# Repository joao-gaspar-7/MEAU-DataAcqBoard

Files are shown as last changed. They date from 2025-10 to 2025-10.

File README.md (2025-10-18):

# Embedded Hardware Development Workflow

This repository contains a simplified version of the typical workflow when developing hardware for an embedded system based on a microcontroller.

---

## 🧩 Overview

The goal of this repository is to provide an overview of a typical workflow for:

- **Requirement definition stage** (system specifications, component selection, definition of validation tests)
- **Hardware design stage** (schematics, PCB layout, and fabrication)
- **Testing and validation stage** (board bring-up, unit, integration, and HIL testing)

---

## 📁 Repository Structure

<pre>
├── <a href="0_Requirements">0_Requirements/</a>
│
├── <a href="1_Design-Data">1_Design-Data/</a>
│   ├── <a href="1_Design-Data/0_Hardware">0_Hardware/</a>
│   │   ├── <a href="1_Design-Data/0_Hardware/0_pre-schematic-reports">0_pre-schematic-reports/</a>
│   │   ├── <a href="1_Design-Data/0_Hardware/1_schematic">1_schematic/</a>
│   │   ├── <a href="1_Design-Data/0_Hardware/2_pcb">2_pcb/</a>
│   │   └── <a href="1_Design-Data/0_Hardware/3_fabrication-files">3_fabrication-files/</a>
│   │
│   └── <a href="1_Design-Data/1_Firmware">1_Firmware/</a> <i>(used in hybrid repositories)</i>
│
└── <a href="2_Validation">2_Validation/</a>
</pre>

---

## ⚙️ Hardware Development Workflow

1. **Requirements Definition**
   - Define top level requirements (e.g. number of inputs/outputs and or necessary communication protocols)
   - Specify MCU variant (e.g., ESP32-WROOM-32, ESP32-S3, STM32F4, etc).
   - Define I/O mapping and required peripherals (CAN, SPI, Wi-Fi, sensors, etc.).

2. **Schematic Design**
   - Tools: Altium Designer.
   - Use reference hardware design guidelines from Espressif/ST/others.
   - Include power regulation, input and output stages and any required physical communication layer (CAN, SPI, I2C).

3. **PCB Layout**
   - Follow each manufacturers design rules for trace length, component placement, ground planes, etc.
   - Perform DRC and ERC checks before Gerber generation.

4. **Fabrication & Assembly**
   - Export Gerbers, pick-and-place, and BOM files.
   - Validate part availability using component sourcing tools.

5. **Hardware Bring-Up**
   - Validate power rails, USB-UART communication, and flash memory.
   - Use adequate IDE to test module's IOs and peripherals with simple base code.

---

## 🧰 Tools and Dependencies

| Category | Tool | Description |
|---|---|---|
| Hardware | Altium | Schematic & PCB design |
| Firmware | PlatformIO or STM32CubeIDE | Build and deployment environment |
| Documentation | Doxygen / MkDocs | Code and design documentation |

---

## 📚 Documentation

- [Requirements Report](0_Requirements/0_Requirements-Report.pdf)
- [MCU Mapping Report](1_Design-Data/0_Hardware/0_pre-schematic-reports/0_MCU-Mapping-Report.pdf)
- [Validation Report](2_Validation/0_Validation-Report.pdf)

---

**Author:** [Joao Gaspar](https://github.com/joao-gaspar-7)
**Last Updated:** October 2025

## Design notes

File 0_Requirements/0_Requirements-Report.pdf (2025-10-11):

Organisation: IPLeiria | Date: 08/02/2024
Customer: NA | Project: Master Thesis
Team: NA | Ref: MEAU-DataAcqBoard
MEAU-DataAcqBoard | 1

## Requirements Report

### 1 Job data

Type | Location | Reference
Requirements report | Leiria | MEAU-DataAcqBoard
Done by | Start date | End date
Joao Gaspar | 08/02/2024 | 08/02/2024

## Brief

The current document provides the established requirements for MEAU-DataAcqBoard project.

### 2 Requirements

2.1 | Develop microcontroller based module (familiarity, ease of deployment, enough processing power)
2.2 | Capable of acquiring at least 10 analog signals (NTCs) and 1 digital signal (flow meter)
2.3 | Analog signal voltage reading error must not exceed 5%
2.4 | Capable of storing the acquired data in permanent storage at 2Hz
2.5 | Capable of displaying acquired data to user in a timely manner (test safety control in real time)
2.6 | Hardware to enable manual control of data acquisition start/stop

### 3 Optional Features

3.1 Implementation of CAN Bus to allow future use as datalogger of data generated elsewhere

3.2

Power outputs (+12V) to allow board to drive cooling accessories.

Water Pump output is to be used to generate a PWM signal to set pump speed only. (Output current rating: 1A)

Fan output is to be used to supply power to a fan with a current rating of 0.3A. (Output current rating: 1A)

Extra power output may be used to power other loads. (Output current rating: 2A)

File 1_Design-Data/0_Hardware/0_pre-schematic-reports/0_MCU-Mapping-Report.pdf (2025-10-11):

Organisation: IPLeiria | Date: 10/02/2024
Customer: NA | Project: Master Thesis
Team: NA | Ref: MEAU-DataAcqBoard
MEAU-DataAcqBoard | 1

## MCU Mapping Report

### 1 Job data

Type | Location | Reference
MCU mapping report | Leiria | MEAU-DataAcqBoard
Done by | Start date | End date
Joao Gaspar | 10/02/2024 | 10/02/2024

## Brief

The current document provides a summary of the decisions made to generate the MCU pin mapping, considering all requirements established in the Requirements Report.

### 2 Requirements

2.1 Develop microcontroller based module (familiarity, ease of deployment, enough processing power)

Solution Selected ESP32 as processing unit for the module. Robust hardware and firmware design support.

2.2 Capable of acquiring at least 10 analog signals (NTCs) and 1 digital signal (flow meter)

Solution | Resorted to both ESP32 GPIOs and ADC expander to acquire a total of 13 inputs.
| • 10 NTC sensor inputs (analog) • 1 Flow Meter input (digital) • 1 Generic input (analog/digital) • 1 User START button (digital)
| To read said signals the following strategy was adopted:
1. Deployed MCP3008 as the ADC expander. This device will read 8 NTC. This device will
| require implementing SPI bus.
2. Remaining inputs (both analog and digital) to be mapped to ESP32. Map all said inputs to
| input only IOs.

Team: NA | Ref: MEAU-DataAcqBoard

### 2.3 Analog signal voltage reading error must not exceed 5%

Solution All signals to be read will be condition to range between 0 - 3.3V. This means that to meet this requirement all read signal voltages must be within ±0.165V of the real value.

1. Based on previous experience using the ESP’s ADC it is expected that a correction value will
| need to be applied.
2. The ADC expander has a resolution of 10bits, resulting in a resolution of 0.0032V per ADC bit. It
| is expected that an error less than 5% will be easily achievable with minimal calibration.

### 2.4 Capable of storing the acquired data in permanent storage at 2Hz

Solution Deploy SD Card for permanent log file storage. This requires adding a second CS pin to control data flow to the SD Card.

2.5 Capable of displaying acquired data to user in a timely manner (test safety control in real time)

Solution The flashing UART interface used by PlatformIO will be capable of meeting this requirement if new data lines are kept at least 100ms apart. This data frequency (10Hz) is enough to keep track of real time test conditions.

### 2.6 Hardware to enable manual control of data acquisition start/stop

Solution Deploy a user button mapped to one of the input-only ESP pins.

Team: NA | Ref: MEAU-DataAcqBoard

### 3 Optional Features

3.1 | Implementation of CAN Bus to allow future use as datalogger of data generated elsewhere
Solution | Deploy CAN support hardware.
1. TJA1441ATK-0Z CAN transceiver.
2. RC filter between CAN H and CAN L lines.

3.2

Power outputs (+12V) to allow board to drive cooling accessories.

Water Pump output is to be used to generate a PWM signal to set pump speed only. (Output current rating: 1A)

Fan output is to be used to supply power to a fan with a current rating of 0.3A. (Output current rating: 1A)

Extra power output may be used to power other loads. (Output current rating: 2A)

Solution Deploy MOSFET+Driver setup for each power output to enable faster response when using PWM to drive these outputs.

1. MCP1407-E/MF MOSFET driver
2. PMV15UNEAR MOSFET (rated for 6A of current)

Team: NA | Ref: MEAU-DataAcqBoard

### 4 MCU Mapping

Taking into consideration the decisions made in points 2 and 3, the MCU’s pins were mapped to specific functions. These are exposed in the tables below.

Table 1 – MCU mapping color code caption
Color code | Meaning Generic IO Input only Flash only pins

Table 2 – MCU mapping
ESP pad | Designator | Functionality/Peripheral
1 | VDDA | Power
2 | LNA_IN | Wi-Fi/Bluetooth Antenna Signal
3 | VDDA3P3 | Power
4 | VDDA3P3 | Power
5 | SENSOR_VP (IO36) | Extra Filtered Signal (MCU_AIN1)
6 | SENSOR_CAPP (IO37) | Unconnected
7 | SENSOR_CAPN (IO38) | Unconnected
8 | SENSOR_VN (IO39) | Unconnected
9 | EN | ESP Reset Pin
10 | IO34 | NTC9 Filtered Signal (MCU_AIN2)
11 | IO35 | Flow Meter Filtered Signal (MCU_AIN3)
12 | IO32 | NTC8 Filtered Signal (MCU_AIN0)
13 | IO33 | User Button Digital Input (MCU_D3)
14 | IO25 | SPI (SD Card CS pin)
15 | IO26 | Water Pump PWM - Digital Output (MCU_D0)
16 | IO27 | Test Point
17 | IO14 | Unconnected
18 | IO12 | Test Point
19 | VDD3P3_RTC | Power
20 | IO13 | CAN (CAN_RX - TJA1441ATK-0Z pin 4)
21 | IO15 | CAN (CAN_TX - TJA1441ATK-0Z pin 1)
22 | IO2 | Test Point
23 | IO0 | ESP Boot pin
24 | IO4 | General Purpose LED
25 | IO16 | Unconnected
26 | VDD_SDIO | Power
27 | IO17 | Unconnected
28 | SD2 | Unconnected
29 | SD3 | Unconnected
30 | CMD | Unconnected
31 | CLK | Unconnected
32 | SD0 | Unconnected
33 | SD1 | Unconnected
34 | IO5 | SPI (ADC Expander CS pin)
35 | IO18 | SPI (SCLK pin)
36 | IO23 | SPI (MOSI pin)

Team: NA | Ref: MEAU-DataAcqBoard

### 4 MCU Mapping (continued)

Table 2 – MCU mapping (continued)
37 | VDD3P3_CPU | Power
38 | IO19 | SPI (MISO pin)
39 | IO22 | FAN Power - Digital Output (MCU_D1)
40 | U0RXD | UART1 (PlatformIO flashing interface)
41 | U0TXD | UART1 (PlatformIO flashing interface)
42 | IO21 | Extra Power Output - Digital Output (MCU_D2)
43 | VDDA | Power
44 | XTAL_N_NC | Unconnected
45 | XTAL_P_NC | Unconnected
46 | VDDA | Power
47 | CAP2_NC | Unconnected
48 | CAP1_NC | Unconnected
49 | GND | Ground pad

### 5 Summary

The pin mapping allocates:

- 5 inputs via ESP32 ADC
- 8 analog inputs via MCP3008 SPI ADC
- 3 digital outputs for power control
- 3 communication interfaces (SPI, UART, CAN)

All mandatory requirements are addressed with 1 extra output, 1 extra input and 3 ESP32 pins accessible via test points, available for future expansion.

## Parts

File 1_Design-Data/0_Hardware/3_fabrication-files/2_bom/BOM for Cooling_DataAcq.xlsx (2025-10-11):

Comment | Designator | Footprint
150080RS75000 | 3V3, 5V | 0805led_V2
EVP-AWED4A | BOOT, RESET, START | 0403MM_SWITCH
C0603C104Z3VAC7411 | C1, C4, C21 | 0603_CAP
CL10A106MQ8NNNL | C2 | 0603_CAP
EMK107B7105MA-T | C3, C10 | 0603_CAP
EMK107B7105MA-T | C5 | 0603_CAP
JMK212BBJ226MG8T | C6, C7, C8, C9, C17, C18, C19, C20, C26, C27, C28, C29 | 0805CAP_V2
VJ0603A101JXJCW1BC | C11 | 0603_CAP
CL03A104KP3NNNH | C12 | 0603_CAP
0805N2R7C500CT | C15 | 0805CAP_V2
0805N4R7C101CT | C16 | 0805CAP_V2
CL21A106KAYNNNG | C24, C25 | 0805CAP_V2
C0805C104M5RACTU | C30, C31 | 0805CAP_V2
JMK212BBJ226MG8T | C32, C33, C34, C35, C37 | 0805CAP_V2
UMK212B7105KGHT | C36 | 0805CAP_V2
Cap | C38 | 0805CAP_V2
Cap | C39 | 0805CAP_V2
08052C472KAT2A | C40 | 0805CAP_V2
SD0805S020S1R0 | D1 | 0805DIODE
BZY55B3V3_RYG | D2, D3 | 0805zener_V2
VSSAF5L45HM3_A_H | D4 | DO-221_v2
0ZCG0200AF2B | F1 | FUSC4632X155N
CP2102N-A02-GQFN24 | IC1 | QFN50P400X400X80-25N-D
BC847BDW1T1G | IC2 | SOT65P210X110-6N
ESP32-PICO-D4 | IC3 | ESP32-PICO-D4_CLEAN_V3
TPS54394RSAR | IC4 | TPS54394RSAR
MCP3008T-I_SL | IC5 | SOIC-16
MIC5219-3.3YM5-TR | IC6 | MIC5219
MCP1407-E_MF | IC7, IC8, IC10 | SON127P600X500X100-9N-D
TJA1441ATK_0Z | IC9 | TJA1441ATK_0Z
TestPoint | IO2, IO12, IO27, MISO, MOSI, SCLK | 1_TestPoint
2201778-1 | J1 | SD_11mm_22017781_v2
10-08-1101 | J2, J5, J6 | TERMINAL_10PIN_V3
10-08-1041 | J3 | TERMINAL_4PIN_V3
5747844-6 | J4 | D-Sub 9 Position
CWF1610-2R2K | L1 | 0603_CAP
AIMC-0805-1N5S-T | L2 | 0805COIL_V2
IHLP2020BZER4R7M11 | L3 | 2020 Inductor
IHLP2020BZER3R3M01 | L4 | 2020 Inductor
IN-S85AT5UW | ON | 0805led_V2
PRO-OB-440 | PRO-OB-1 | PRO-OB-440_withKeepout
PMV15UNEAR | Q1, Q2, Q3 | TO-263-3
292-10K-RC | R1, R2, R3, R4, R5, R6, R7, R8, R10, R11, R12, R13, R15, R16, R17, R18, R23, R24, R25, R26, R27, R28, R29, R30 | 0805RES_V2
Res1 | R9, R14, R19, R20 | 0805RES_V2
Res1 | R21 | 0805RES_V2
Res1 | R22 | 0805RES_V2
ERJ-6ENF2211V | R31 | 0805RES_V2
ERJ-6ENF2211V | R32 | 0805RES_V2
Res1 | R33, R34, R41, R44, R50, R52, R53, R54, R55 | 0805RES_V2
1623131-1 | R35, R38, R42 | 0805RES_V2
ERJ-6ENF2212V | R36, R39 | 0805RES_V2
ERJ-6ENF7322V | R37 | 0805RES_V2
CR0805-FX-1243ELF | R40 | 0805RES_V2
NC | R43, R49, R51 | 0805RES_V2
RK73H2ATTD60R4F | R45, R46 | 0805RES_V2
WR08X000PGL | R47, R48 | 0805RES_V2
2013499-1 | USB1 | TE_2013499-1

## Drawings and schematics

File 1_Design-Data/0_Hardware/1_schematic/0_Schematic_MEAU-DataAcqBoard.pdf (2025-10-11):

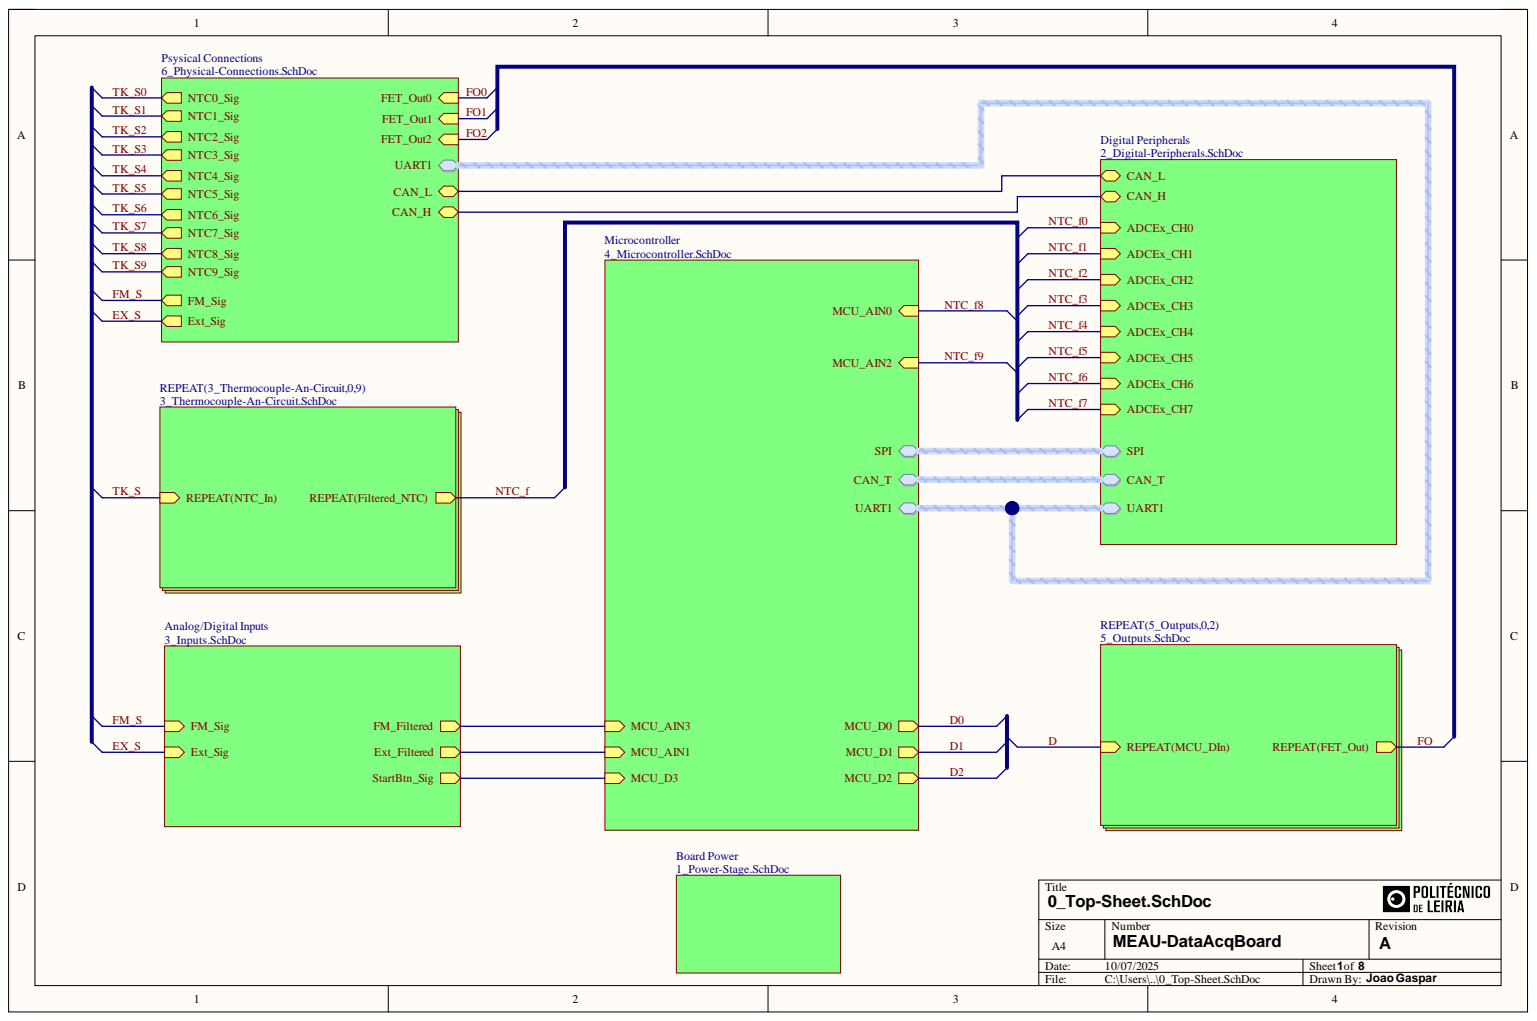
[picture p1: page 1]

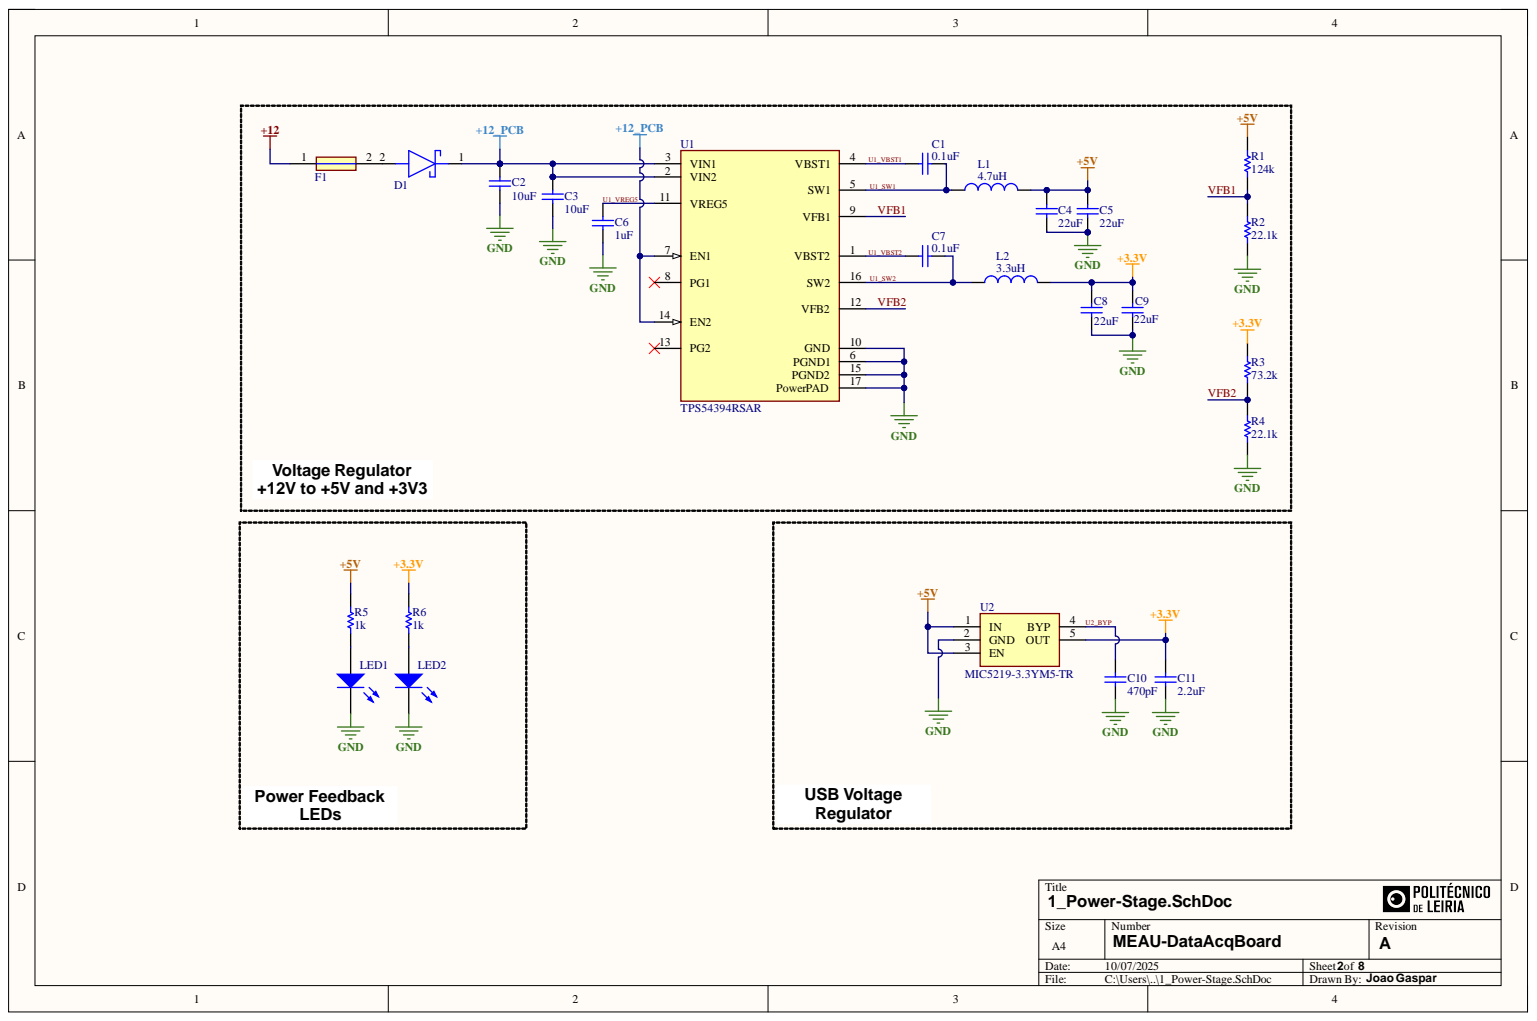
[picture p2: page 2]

VREG5 11

EN2 14 | VFB2

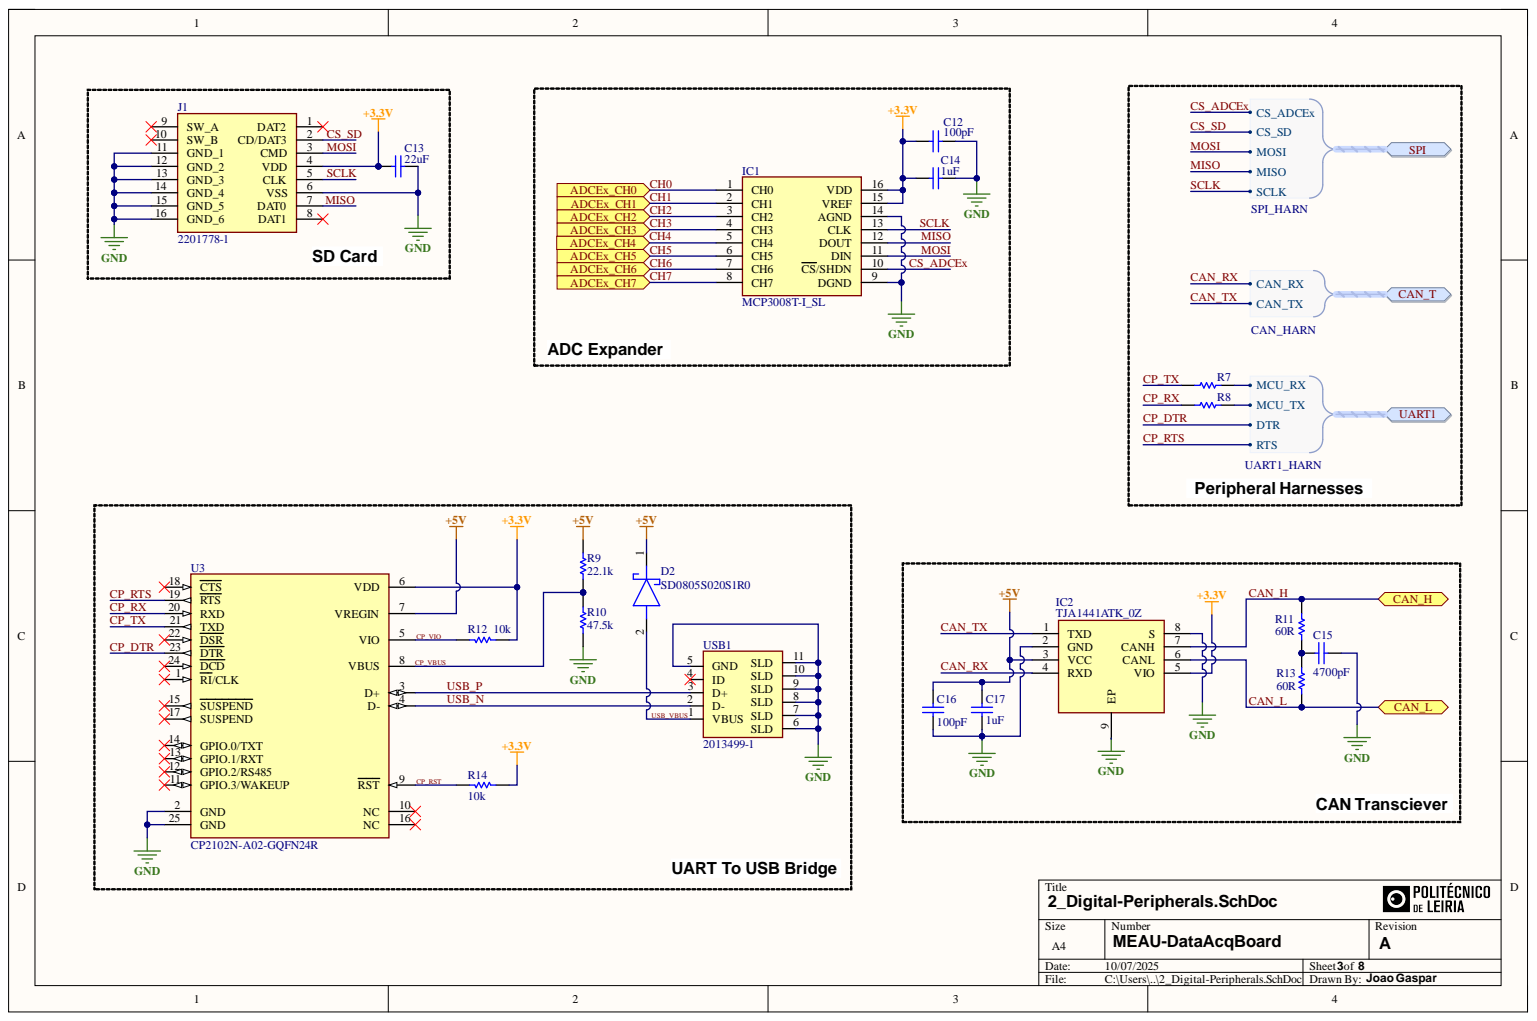
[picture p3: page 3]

UART To USB Bridge

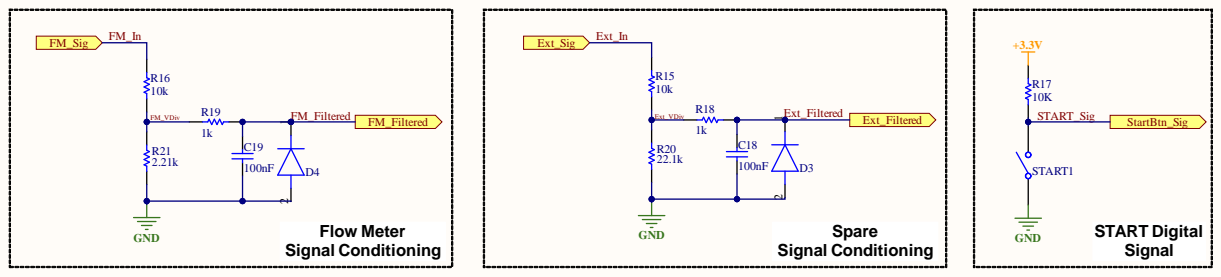
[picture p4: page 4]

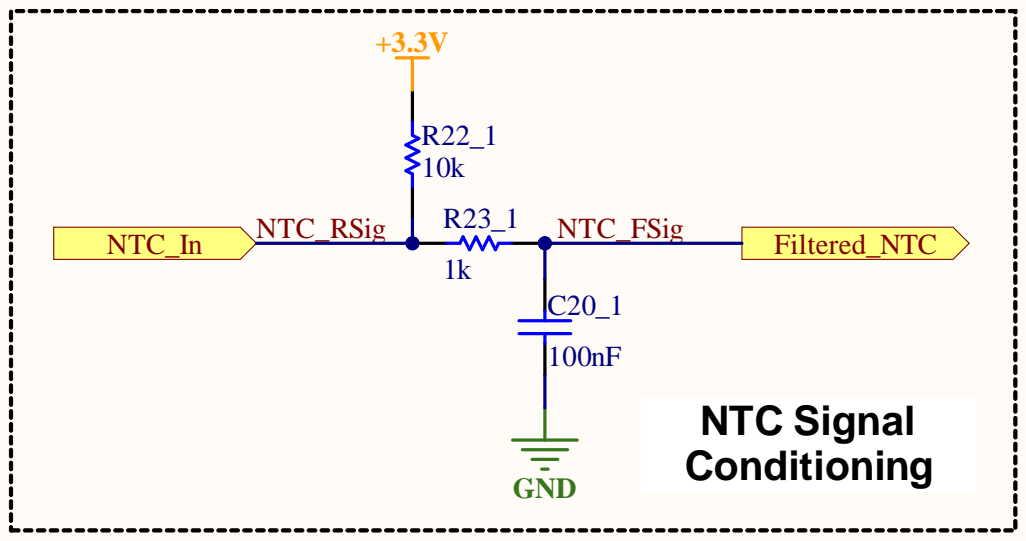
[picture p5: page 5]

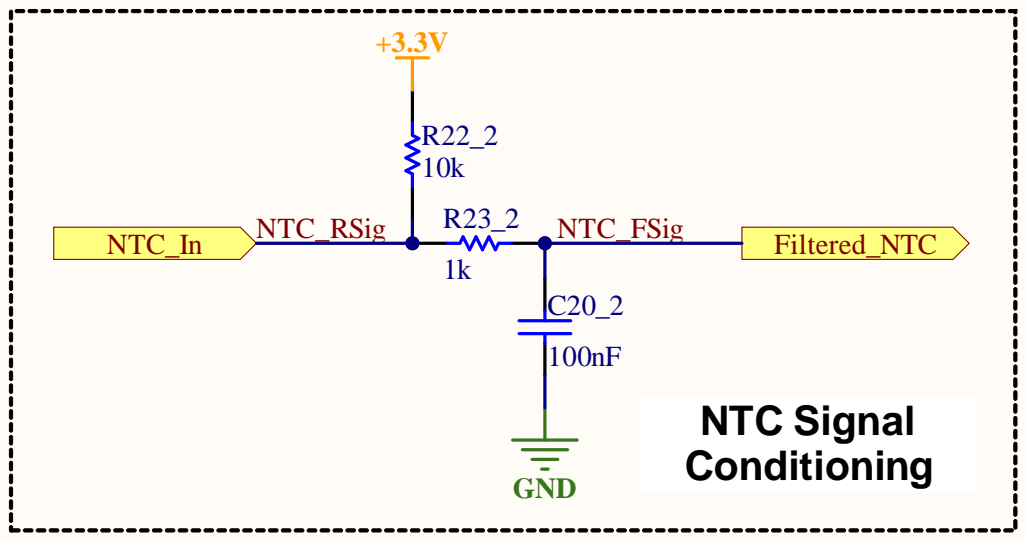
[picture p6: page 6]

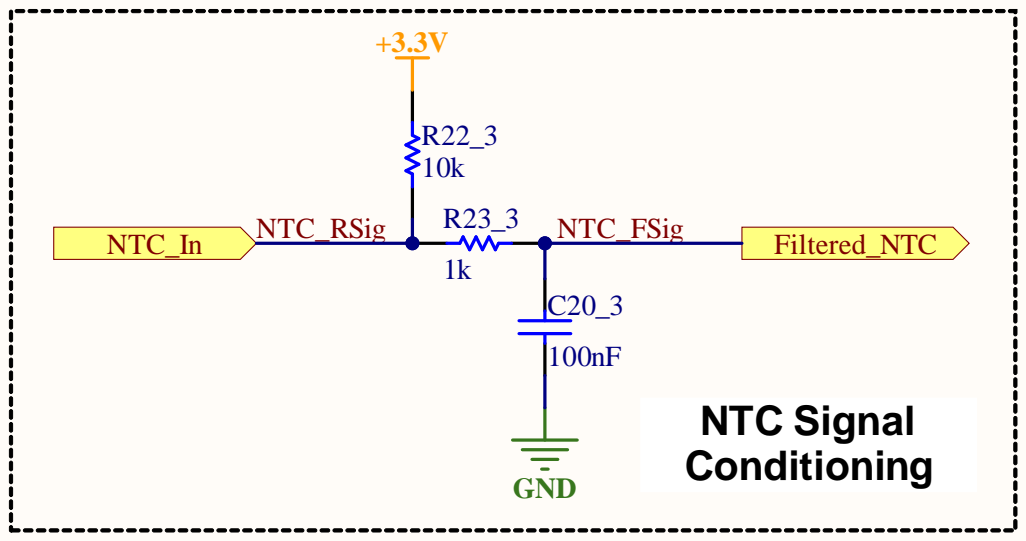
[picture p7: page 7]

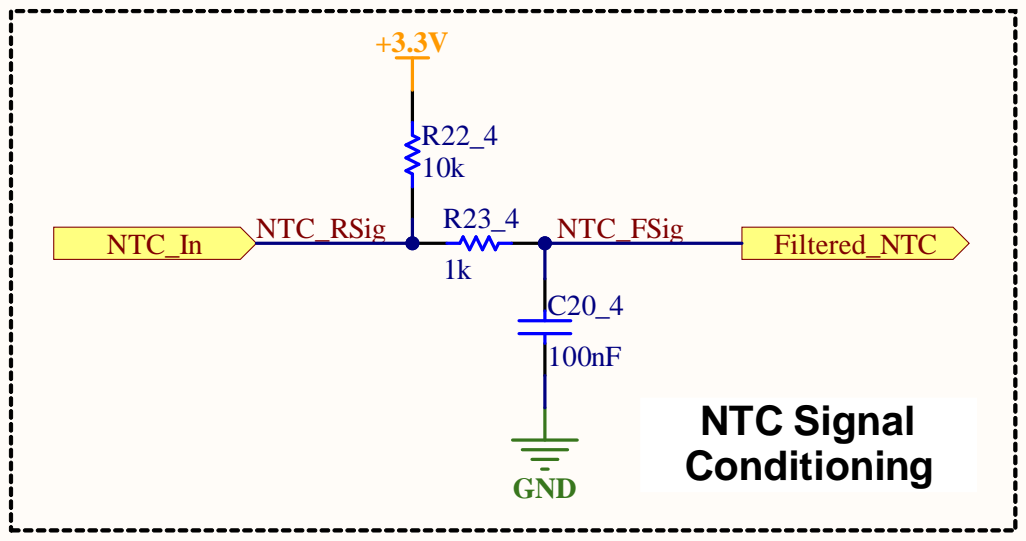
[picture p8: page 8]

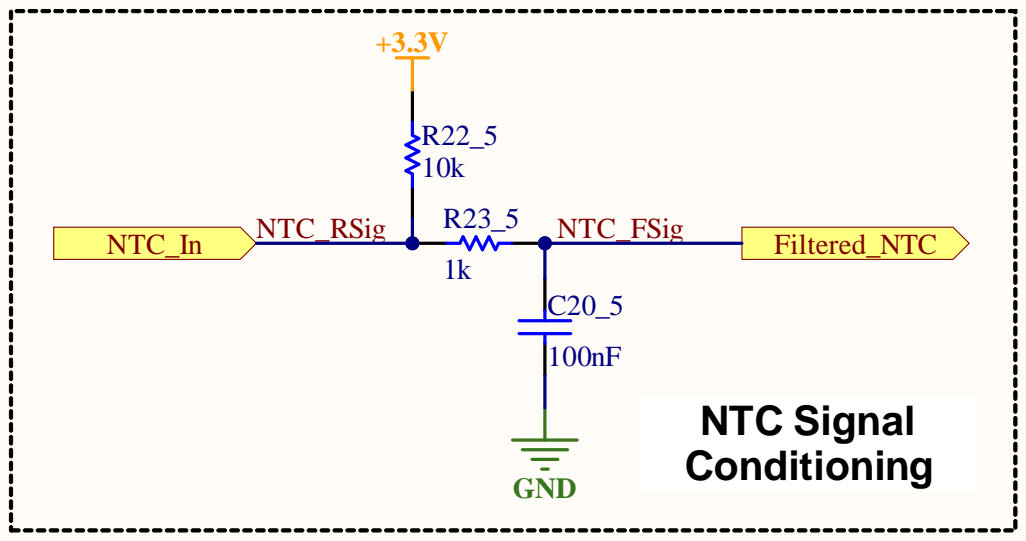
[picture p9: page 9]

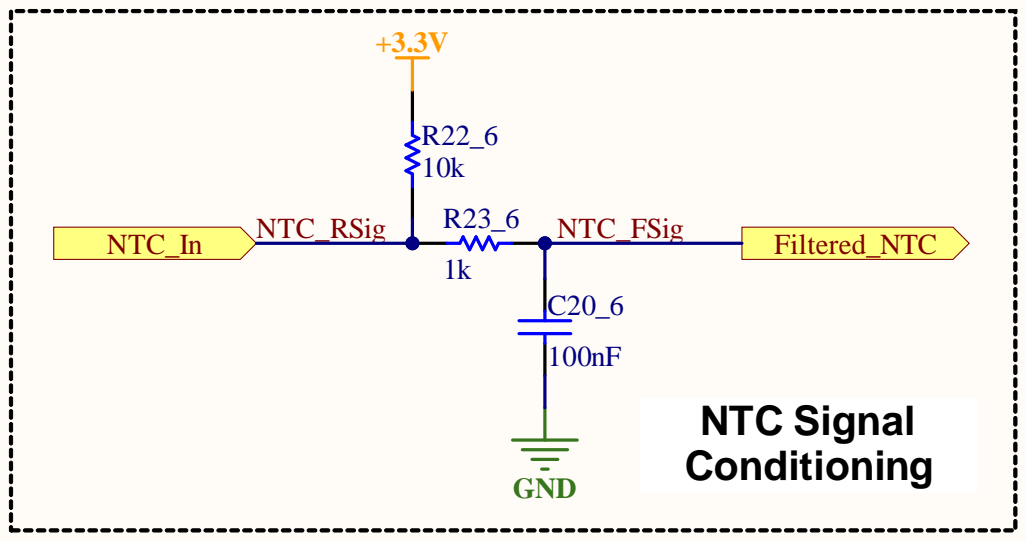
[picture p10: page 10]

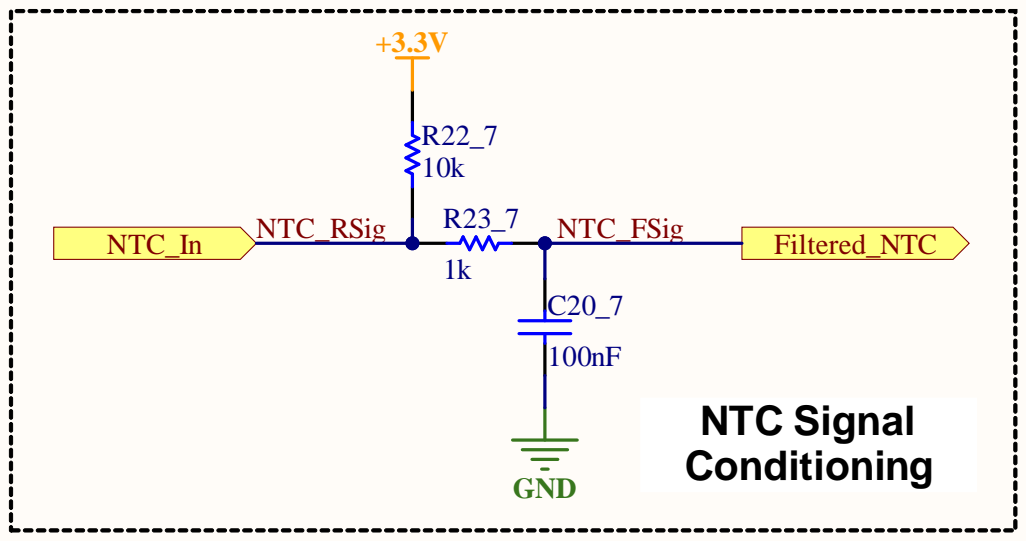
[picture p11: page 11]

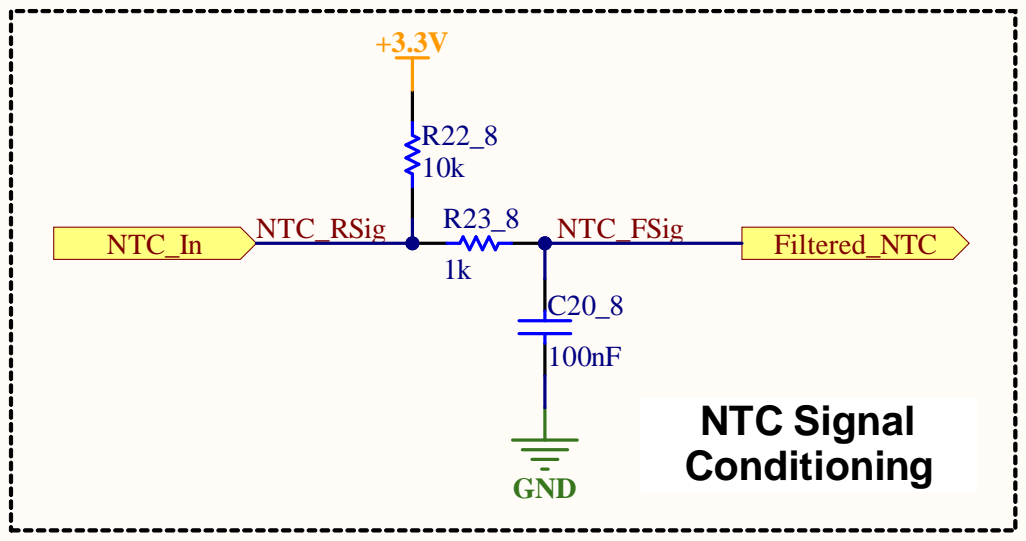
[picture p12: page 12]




I3 6 MCU _ A IN 1 E N | 2 5





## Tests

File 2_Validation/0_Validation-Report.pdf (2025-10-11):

Organisation: IPLeiria | Date: 24/02/2024
Customer: NA | Project: Master Thesis
Team: NA | Ref: MEAU-DataAcqBoard
MEAU-DataAcqBoard | 1

## Validation Report

### 1 Job data

Type | Location | Reference
Validation report | Leiria | MEAU-DataAcqBoard
Done by | Start date | End date
Joao Gaspar | 24/02/2024 | 24/02/2024

## Brief

The current document provides a summary of the validation tests/checks done in the context of MEAU-DataAcqBoard project.

Each solution is evaluated OK/NOK depending on whether the validation results met/didn’t meet the established requirements.

### 2 Requirements

2.1 Develop microcontroller based module (familiarity, ease of deployment, enough processing power)

Solution

OK

Selected ESP32 as processing unit for the module. Robust hardware and firmware design support.

2.2 Capable of acquiring at least 10 analog signals (NTCs) and 1 digital signal (flow meter)

Solution

OK

Resorted to both ESP32 GPIOs and ADC expander to acquire a total of 13 inputs.

- 10 NTC sensor inputs (analog)
- 1 Flow Meter input (digital)
- 1 Generic input (analog/digital)
- 1 User START button (digital)

Team: NA | Ref: MEAU-DataAcqBoard

### 2.3 Analog signal voltage reading error must not exceed 5%

Solution

OK

Calibration tests were run to determine voltage offset between the values obtained by the module and the real NTC voltage value measured with oscilloscope.

Calibration tests consisted in:
1. Submerging the NTC that was connected to the module in boiling water.
2. Voltage values from the ESP32 GPIOs, the ADC expander and the oscilloscope were registered at intervals of 0.1V of NTC signal voltage.
3. Only voltages between 2V and 0.65V were considered, since this signal voltage range represented NTC temperature readings ranging from 15ºC to 65ºC, considering the module’s hardware configuration.

Temperature error percentage before and after correction factors were introduced are compiled below:

The validation tests revealed great accuracy from the ADC expander, having been measured an average error across the relevant voltage range and across all channels of 2,52%. Below there follows a chart of voltage reading error per expander channel:

0%

5%

10%

15%

20%

25%

30%

1,999 1,895 1,803 1,703 1,603 1,505 1,407 1,319 1,192 1,088 0,961 0,889 0,737 0,655

## Error Value [%]

## NTC Signal [V]

# Temperature Error Comparison (ESP32 GPIOs)

### Initial Error Error after calibration

0,0%

0,5%

1,0%

1,5%

2,0%

2,5%

3,0%

3,5%

CH0 | CH1 | CH2 | CH3 | CH4 | CH5 | CH6 | CH7

### Error of Voltage Reading [%]

### Expander Channel

# ADC Expander Reading Error

Team: NA | Ref: MEAU-DataAcqBoard

### 2.4 Capable of storing the acquired data in permanent storage at 2Hz

Solution

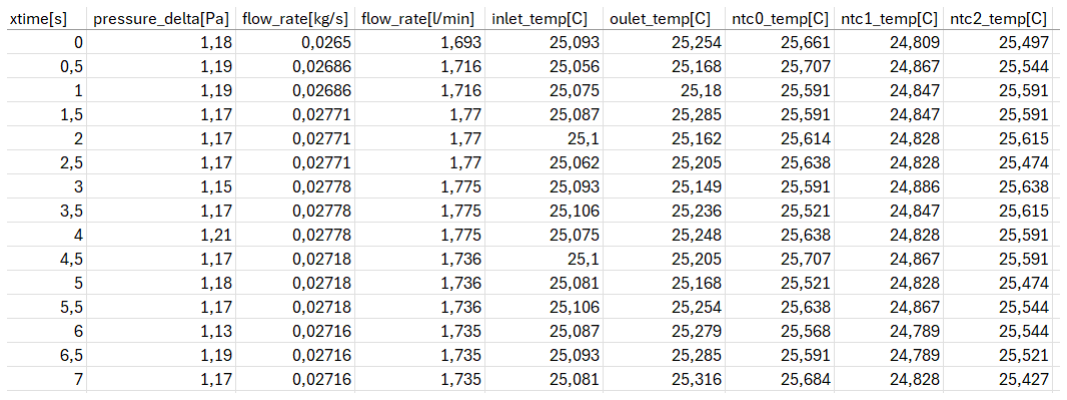
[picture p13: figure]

OK

Verified with data from log files. Time delta between each stored sample matches the requirement.

2.5 Capable of displaying acquired data to user in a timely manner (test safety control in real time)

Solution

OK

Verified in the timestamps of each UART message. Time delta between each message stayed at a steady 500ms during a continuous 20 minute test.

### 2.6 Hardware to enable manual control of data acquisition start/stop

Solution

OK

Deployed a user button which was set as a toggle for the current data acquisition state in firmware.

Team: NA | Ref: MEAU-DataAcqBoard

### 3 Optional Features

3.1 Implementation of CAN Bus to allow future use as datalogger of data generated elsewhere

Solution

OK

| CAN support hardware (transceiver and noise filter) were deployed in board design.
| Validated with a basic CAN example. Not in use in the firmware version that will run during the BTMS bench test.

3.2

Power outputs (+12V) to allow board to drive cooling accessories.

Water Pump output is to be used to generate a PWM signal to set pump speed only. (Output current rating: 1A)

Fan output is to be used to supply power to a fan with a current rating of 0.3A. (Output current rating: 1A)

Extra power output may be used to power other loads. (Output current rating: 2A)

Solution

OK

Implemented a total of 3 high-side MOSFETs actuated with MOSFET drivers for greater reliability.

All power outputs were submitted to a basic load test at their current ratings. Load tests consisted in:

1. Supplying +12V to a power resistor for 15 minutes with each individual power output.
2. A power resistor of 10Ω was used to test the Water Pump and Fan outputs.
3. A power resistor of 5Ω was used to test the Extra output.

Having tested each individual output board temperature rise did not exceed 10ºC.

Not in use in the firmware version that will run during the BTMS bench test.

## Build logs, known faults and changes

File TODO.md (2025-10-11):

# TODO List

This is the TODO template to be use during the development to track project tasks.

This file tracks pending features, bug fixes, and cleanup tasks for the project.  
Format:
- `[ ]` = not started  
- `[x]` = completed  
- `P1` = high priority, `P2` = medium, `P3` = low  

---

## Project Overview

**Project Name:** PROJECT-ID 

**Last Updated:** 2025-09-29

---

## Features

[x] **P1** Add routine to save relevant machine_state members to EERPOM (implemented solution relies on VCU EEPROM to save Drive Profile data - see aa_can_nvm_data)

[x] **P2** Add routine to configure/load data from RTC

[x] **P2** Add routine that updates machine_state time and date members from RTC values at boot (time and date members of machine_state were separated into their own struct to avoid racing conditions)

[x] **P1** Finish integration of remaining error messages from BMS

---

## Bugs

[x] **P2** Swap "+" and "-" buttons on page 2 of Drive Profile Setup Screen (visually only)

---

## Refactoring / Cleanup

---

## Testing

---

## Notes / Links
- Link to project documentation:
- Related issue tracker / repo:

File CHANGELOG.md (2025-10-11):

# Changelog

All notable changes to this project will be documented in this file. 

This is the CHANGELOG template to be use during the development to track repository level changes. In hybrid repositories individual changelogs (one for hardware and another for fimrware).

The format is based on [Keep a Changelog](https://keepachangelog.com/en/1.1.0/),
and this project adheres to [Semantic Versioning](https://semver.org/spec/v2.0.0.html).

## [Unreleased]

### Added

- v1.1 Brazilian Portuguese translation.
- v1.1 German Translation
- v1.1 Spanish translation.
- v1.1 Italian translation.
- v1.1 Polish translation.
- v1.1 Ukrainian translation.

### Changed

- Use frontmatter title & description in each language version template
- Replace broken OpenGraph image with an appropriately-sized Keep a Changelog 
  image that will render properly (although in English for all languages)
- Fix OpenGraph title & description for all languages so the title and 
description when links are shared are language-appropriate

### Removed

- Trademark sign previously shown after the project description in version 
0.3.0

## [1.1.1] - 2023-03-05

### Added

- Arabic translation (#444).
- v1.1 French translation.
- v1.1 Dutch translation (#371).
- v1.1 Russian translation (#410).
- v1.1 Japanese translation (#363).
- v1.1 Norwegian Bokmål translation (#383).
- v1.1 "Inconsistent Changes" Turkish translation (#347).
- Default to most recent versions available for each languages.
- Display count of available translations (26 to date!).
- Centralize all links into `/data/links.json` so they can be updated easily.

### Fixed

- Improve French translation (#377).
- Improve id-ID translation (#416).
- Improve Persian translation (#457).
- Improve Russian translation (#408).
- Improve Swedish title (#419).
- Improve zh-CN translation (#359).
- Improve French translation (#357).
- Improve zh-TW translation (#360, #355).
- Improve Spanish (es-ES) transltion (#362).
- Foldout menu in Dutch translation (#371).
- Missing periods at the end of each change (#451).
- Fix missing logo in 1.1 pages.
- Display notice when translation isn't for most recent version.
- Various broken links, page versions, and indentations.

### Changed

- Upgrade dependencies: Ruby 3.2.1, Middleman, etc.

### Removed

- Unused normalize.css file.
- Identical links assigned in each translation file.
- Duplicate index file for the english version.

## [1.1.0] - 2019-02-15

### Added

- Danish translation (#297).
- Georgian translation from (#337).
- Changelog inconsistency section in Bad Practices.

### Fixed

- Italian translation (#332).
- Indonesian translation (#336).

## [1.0.0] - 2017-06-20

### Added

- New visual identity by [@tylerfortune8](https://github.com/tylerfortune8).
- Version navigation.
- Links to latest released version in previous versions.
- "Why keep a changelog?" section.
- "Who needs a changelog?" section.
- "How do I make a changelog?" section.
- "Frequently Asked Questions" section.
- New "Guiding Principles" sub-section to "How do I make a changelog?".
- Simplified and Traditional Chinese translations from [@tianshuo](https://github.com/tianshuo).
- German translation from [@mpbzh](https://github.com/mpbzh) & [@Art4](https://github.com/Art4).
- Italian translation from [@azkidenz](https://github.com/azkidenz).
- Swedish translation from [@magol](https://github.com/magol).
- Turkish translation from [@emreerkan](https://github.com/emreerkan).
- French translation from [@zapashcanon](https://github.com/zapashcanon).
- Brazilian Portuguese translation from [@Webysther](https://github.com/Webysther).
- Polish translation from [@amielucha](https://github.com/amielucha) & [@m-aciek](https://github.com/m-aciek).
- Russian translation from [@aishek](https://github.com/aishek).
- Czech translation from [@h4vry](https://github.com/h4vry).
- Slovak translation from [@jkostolansky](https://github.com/jkostolansky).
- Korean translation from [@pierceh89](https://github.com/pierceh89).
- Croatian translation from [@porx](https://github.com/porx).
- Persian translation from [@Hameds](https://github.com/Hameds).
- Ukrainian translation from [@osadchyi-s](https://github.com/osadchyi-s).

### Changed

- Start using "changelog" over "change log" since it's the common usage.
- Start versioning based on the current English version at 0.3.0 to help
  translation authors keep things up-to-date.
- Rewrite "What makes unicorns cry?" section.
- Rewrite "Ignoring Deprecations" sub-section to clarify the ideal
  scenario.
- Improve "Commit log diffs" sub-section to further argument against
  them.
- Merge "Why can’t people just use a git log diff?" with "Commit log
  diffs".
- Fix typos in Simplified Chinese and Traditional Chinese translations.
- Fix typos in Brazilian Portuguese translation.
- Fix typos in Turkish translation.
- Fix typos in Czech translation.
- Fix typos in Swedish translation.
- Improve phrasing in French translation.
- Fix phrasing and spelling in German translation.

### Removed

- Section about "changelog" vs "CHANGELOG".

## [0.3.0] - 2015-12-03

### Added

- RU translation from [@aishek](https://github.com/aishek).
- pt-BR translation from [@tallesl](https://github.com/tallesl).
- es-ES translation from [@ZeliosAriex](https://github.com/ZeliosAriex).

## [0.2.0] - 2015-10-06

### Changed

- Remove exclusionary mentions of "open source" since this project can
  benefit both "open" and "closed" source projects equally.

## [0.1.0] - 2015-10-06

### Added

- Answer "Should you ever rewrite a change log?".

### Changed

- Improve argument against commit logs.
- Start following [SemVer](https://semver.org) properly.

## [0.0.8] - 2015-02-17

### Changed

- Update year to match in every README example.
- Reluctantly stop making fun of Brits only, since most of the world
  writes dates in a strange way.

### Fixed

- Fix typos in recent README changes.
- Update outdated unreleased diff link.

## [0.0.7] - 2015-02-16

### Added

- Link, and make it obvious that date format is ISO 8601.

### Changed

- Clarified the section on "Is there a standard change log format?".

### Fixed

- Fix Markdown links to tag comparison URL with footnote-style links.

## [0.0.6] - 2014-12-12

### Added

- README section on "yanked" releases.

## [0.0.5] - 2014-08-09

### Added

- Markdown links to version tags on release headings.
- Unreleased section to gather unreleased changes and encourage note
  keeping prior to releases.

## [0.0.4] - 2014-08-09

### Added

- Better explanation of the difference between the file ("CHANGELOG")
  and its function "the change log".

### Changed

- Refer to a "change log" instead of a "CHANGELOG" throughout the site
  to differentiate between the file and the purpose of the file — the
  logging of changes.

### Removed

- Remove empty sections from CHANGELOG, they occupy too much space and
  create too much noise in the file. People will have to assume that the
  missing sections were intentionally left out because they contained no
  notable changes.

## [0.0.3] - 2014-08-09

### Added

- "Why should I care?" section mentioning The Changelog podcast.

## [0.0.2] - 2014-07-10

### Added

- Explanation of the recommended reverse chronological release ordering.

## [0.0.1] - 2014-05-31

### Added

- This CHANGELOG file to hopefully serve as an evolving example of a
  standardized open source project CHANGELOG.
- CNAME file to enable GitHub Pages custom domain.
- README now contains answers to common questions about CHANGELOGs.
- Good examples and basic guidelines, including proper date formatting.
- Counter-examples: "What makes unicorns cry?".

[unreleased]: https://github.com/olivierlacan/keep-a-changelog/compare/v1.1.1...HEAD
[1.1.1]: https://github.com/olivierlacan/keep-a-changelog/compare/v1.1.0...v1.1.1
[1.1.0]: https://github.com/olivierlacan/keep-a-changelog/compare/v1.0.0...v1.1.0
[1.0.0]: https://github.com/olivierlacan/keep-a-changelog/compare/v0.3.0...v1.0.0
[0.3.0]: https://github.com/olivierlacan/keep-a-changelog/compare/v0.2.0...v0.3.0
[0.2.0]: https://github.com/olivierlacan/keep-a-changelog/compare/v0.1.0...v0.2.0
[0.1.0]: https://github.com/olivierlacan/keep-a-changelog/compare/v0.0.8...v0.1.0
[0.0.8]: https://github.com/olivierlacan/keep-a-changelog/compare/v0.0.7...v0.0.8
[0.0.7]: https://github.com/olivierlacan/keep-a-changelog/compare/v0.0.6...v0.0.7
[0.0.6]: https://github.com/olivierlacan/keep-a-changelog/compare/v0.0.5...v0.0.6
[0.0.5]: https://github.com/olivierlacan/keep-a-changelog/compare/v0.0.4...v0.0.5
[0.0.4]: https://github.com/olivierlacan/keep-a-changelog/compare/v0.0.3...v0.0.4
[0.0.3]: https://github.com/olivierlacan/keep-a-changelog/compare/v0.0.2...v0.0.3
[0.0.2]: https://github.com/olivierlacan/keep-a-changelog/compare/v0.0.1...v0.0.2
[0.0.1]: https://github.com/olivierlacan/keep-a-changelog/releases/tag/v0.0.1
